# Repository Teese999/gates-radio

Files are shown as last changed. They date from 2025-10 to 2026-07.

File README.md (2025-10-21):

# Умные Ворота - ESP32 DevKit 38 pin

Проект системы управления воротами через различные каналы связи: 433MHz брелки (включая CAME), Wi-Fi (Алиса через Домовенок Кузя) и GSM.

## 📋 Описание

Устройство на базе **ESP32 DevKit 38 pin** для управления воротами через:
- **433MHz брелки** (включая протокол CAME)
- **Wi-Fi** с интеграцией с Алисой
- **GSM модуль SIM800L** (опционально)
- **Дисплей ST7789** 240x240 для визуального интерфейса
- **Джойстик** для навигации по меню

## 🛠 Компоненты

### Основные компоненты:
- **ESP32 DevKit 38 pin** - основной контроллер
- **Дисплей GMT130-V1.0 (ST7789)** - цветной TFT 240x240
- **Джойстик KS0008** - модуль с двумя осями и кнопкой
- **Радиомодуль SRX882 v1.3** - приемник 433MHz
- **Светодиод** - индикатор импульса
- **GSM модуль SIM800L** - для приема звонков/SMS (опционально)

### Схема подключения:

| Компонент | GPIO | Описание |
|---|---|---|
| Дисплей SCK | GPIO18 | SPI Clock |
| Дисплей MOSI | GPIO23 | SPI Data |
| Дисплей DC | GPIO2 | Data/Command |
| Дисплей RST | GPIO4 | Reset |
| Дисплей CS | GPIO5 | Chip Select |
| Джойстик VRx | GPIO34 | Ось X (ADC) |
| Джойстик VRy | GPIO35 | Ось Y (ADC) |
| Джойстик SW | GPIO14 | Кнопка |
| 433MHz DATA | GPIO13 | Данные с приемника |
| LED | GPIO12 | Светодиод/Реле |
| GSM TX | GPIO16 | UART2 TX |
| GSM RX | GPIO17 | UART2 RX |

## 🚀 Установка и Настройка

### 1. Установка PlatformIO

На macOS используйте Homebrew:

```bash
brew install platformio
```

### 2. Клонирование и сборка

```bash
cd gates-radio
platformio run
```

### 3. Подключение ESP32

Подключите ESP32 к компьютеру через USB. Найдите порт:

```bash
ls /dev/cu.*
```

### 4. Загрузка прошивки

Если ESP32 определился (например, `/dev/cu.usbserial-*`):

```bash
platformio run --target upload
```

Или укажите порт явно:

```bash
platformio run --target upload --upload-port /dev/cu.usbserial-XXXX
```

### 5. Мониторинг Serial

Для просмотра логов:

```bash
platformio device monitor
```

Или с автоматической загрузкой и мониторингом:

```bash
platformio run --target upload && platformio device monitor
```

## 📱 Первоначальная настройка

### Настройка Wi-Fi

1. При первом запуске устройство создаст точку доступа **SmartGate-Config**
2. Пароль: `12345678`
3. Подключитесь к точке доступа и перейдите на `http://192.168.4.1`
4. Введите данные вашей Wi-Fi сети
5. Устройство перезагрузится и подключится к вашей сети

### Добавление 433MHz ключей

1. В меню выберите "Управление ключами"
2. Нажмите кнопку на брелке
3. Код будет отображен в Serial Monitor
4. Используйте веб-интерфейс или джойстик для добавления кода в список доверенных

## 📚 Структура проекта

```
gates-radio/
├── docs.md                    # Полная документация проекта
├── platformio.ini             # Конфигурация PlatformIO
├── include/                   # Заголовочные файлы
│   ├── DisplayManager.h       # Управление дисплеем
│   ├── InputManager.h         # Управление джойстиком
│   ├── RF433Receiver.h        # Прием 433MHz
│   ├── WiFiManager.h          # Управление Wi-Fi
│   ├── GateControl.h          # Управление воротами
│   └── GSMManager.h           # Управление GSM (опционально)
├── src/                       # Исходные файлы
│   ├── main.cpp               # Главный файл
│   ├── DisplayManager.cpp     # Реализация дисплея
│   ├── InputManager.cpp       # Реализация джойстика
│   ├── RF433Receiver.cpp      # Реализация 433MHz
│   ├── WiFiManager.cpp        # Реализация Wi-Fi
│   ├── GateControl.cpp        # Реализация управления
│   └── GSMManager.cpp         # Реализация GSM
└── lib/                       # Библиотеки проекта
```

## 🔧 Используемые библиотеки

- **Adafruit GFX Library** - графическая библиотека
- **Adafruit ST7735 and ST7789 Library** - драйвер дисплея
- **rc-switch** - работа с 433MHz
- **TinyGSM** - работа с GSM модулем
- **Preferences** - хранение настроек (встроенная)
- **WiFi** - работа с Wi-Fi (встроенная)
- **WebServer** - веб-сервер (встроенная)

## 📝 Функциональность

### ✅ Реализовано:
- ✅ Инициализация всех модулей
- ✅ Дисплей с меню
- ✅ Навигация джойстиком
- ✅ Прием 433MHz сигналов
- ✅ Сохранение доверенных ключей
- ✅ Wi-Fi подключение
- ✅ Веб-интерфейс для настройки
- ✅ Управление воротами (импульс на GPIO12)

### 🚧 В разработке:
- 🚧 Интеграция с Алисой (Домовенок Кузя)
- 🚧 Полная реализация GSM модуля
- 🚧 Расширенное меню на дисплее
- 🚧 Добавление/удаление ключей через дисплей

## ⚠️ Важные замечания

### Питание GSM модуля
**ОЧЕНЬ ВАЖНО!** GSM SIM800L требует отдельного источника питания 5V с током до 2А. **НЕ ПИТАЙТЕ** его от ESP32 или USB порта компьютера напрямую!

### Антенна 433MHz
Для стабильной работы приемника припайте антенну длиной ~17 см к антенному пину SRX882.

### Подключение реле
Для реального управления воротами замените светодиод на релейный модуль (1-канальный, 5В с опторазвязкой).

## 🐛 Отладка

### Просмотр логов:
```bash
platformio device monitor --baud 115200
```

### Очистка и пересборка:
```bash
platformio run --target clean
platformio run
```

### Проблемы с портом:
Если ESP32 не определяется, установите драйвер:
- **CH340**: https://github.com/adrianmihalko/ch340g-ch34g-ch34x-mac-os-x-driver
- **CP2102**: https://www.silabs.com/developers/usb-to-uart-bridge-vcp-drivers

## 📖 Дополнительная информация

Полное описание подключения, схемы и детальная документация находятся в файле `docs.md`.

## 🤝 Контакты

Для вопросов и предложений обращайтесь к автору проекта.

## 📄 Лицензия

Проект разработан для личного использования.

---

**Версия:** 1.0.0  
**Дата:** Октябрь 2025  
**Платформа:** ESP32 DevKit 38 pin

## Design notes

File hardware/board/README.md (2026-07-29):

# Монтажная плата «Умные Ворота»

Раскладка устройства на протоплате 100 × 150 мм: где стоит каждый модуль, каким проводом
идёт каждая цепь и в каком порядке всё это паять.

| Файл | Что это |
|---|---|
| `board.json` | Источник правды: плата, зоны, компоненты с пинами, цепи с маршрутами, шаги сборки |
| `index.html` | 3D-вьюер: открывается двойным кликом с диска, крутится мышью, показывает верх и низ платы |
| `viewer.js`, `viewer.css` | Исходники вьюера |
| `build.mjs` | Собирает `index.html`, вшивая в него `board.json` (нужно, потому что `fetch` из `file://` запрещён) |
| `validate.py` | Проверка раскладки: наложения, висящие пины, битые ссылки в шагах |
| `lint_routes.py` | Линт однослойной разводки: наложения проводов, общие пайки, перекрёстки, островок 220 |
| `gen_sheets.py` | Генератор печатных листов: нарезка проводов, зеркальный чертёж низа, прозвонка |
| `assembly-sheets.html` | Сгенерированные листы — печатать и паять |

Правки вносятся **только в `board.json`**, дальше:

```bash
python3 hardware/board/validate.py && python3 hardware/board/lint_routes.py && python3 hardware/board/gen_sheets.py && node hardware/board/build.mjs
```

## Как читать разводку

Разводка однослойная, под платой. Каждая цепь идёт **своим цветом** и **своей полосой** —
два провода нигде не делят коридор или отверстие. Короткие прямые связи — «дорожки»:
голая лужёная проволока, пропаянная на каждом пятачке по пути (в вьюере — серебро с
каплями припоя; кладутся первыми). Всё остальное — изолированный провод. Точки, где
провод проходит **поверх** другой цепи, помечены янтарными кольцами — таких пересечений
50, все перпендикулярные; наложений вдоль и общих паек нет (гарантирует `lint_routes.py`).
Сеть 220 В — только изолированный ПуГВ и только в островке 220.

## Система координат

Отверстие адресуется как `[колонка, ряд]`, начало — левый верхний угол.
Колонки 1…55 идут слева направо и **совпадают с заводской нумерацией 01–55**, напечатанной
вдоль длинных сторон платы; рядов 37 (сверху вниз, 100 мм), шаг 2.54 мм — каждому ряду
соответствует заводская буква у западного края: ряды 1–26 = A–Z, ряды 27–37 = снова A–K.
Овальные столбцы по коротким сторонам в нумерацию не входят («колонка 0» на западе, «56»
на востоке); буквенный край платы = левый край вьюера (сторона GSM). Крепёжные отверстия врезаются в углы сетки — соседние с ними пятачки
не используются.

Модули стоят сверху, вся разводка — снизу. Провода свободно проходят под корпусами модулей,
поэтому в маршруте электрически значимы только те точки, где провод действительно
припаивается: концы и промежуточные пятачки с деталями.

## Почему именно такая раскладка

**Две антенны разнесены по диагонали платы.** CC1101 с разъёмом SMA сидит у правого края,
SIM800L с пигтейлом IPX — у левого; между ними 107 мм. GSM-передатчик в момент регистрации
в сети — самый громкий источник помех в корпусе, а приёмник 433 МГц — самый чувствительный
потребитель тишины. Понижайки, вторые по шумности, тоже отодвинуты от радио.

**Земля — звездой, а не гирляндой.** На макетке земли шли цепочкой через выводы понижаек, и
токи GSM-пиков текли по тем же участкам, что и земля приёмника. Здесь от узла у выхода −V
сетевого модуля расходятся три независимых луча: силовой к эмиттерам транзисторов, GSM
(вход понижайки 4 В) и вход понижайки 5 В. Дальше каждый потребитель возвращает ток своей
паре: земля логики идёт с GND ESP32 парой с проводом 5 В на выход понижайки (минусы входа
и выхода у неизолированного LM2596 — один узел), земля радио подцеплена к земле ESP32,
потому что CC1101 питается от его же 3.3 В — возврат идёт туда, откуда пришло питание.
Отдельный обратный провод для реле, найденный на макетке опытным путём, стал штатным
лучом звезды.

**Путь 4 В к SIM800L — самый короткий силовой на плате** (31 мм по прямой), а конденсатор
2200 мкФ стоит вплотную к пинам модуля. Пики до 2 А берутся из конденсатора, а не тянутся
через плату; иначе модуль перезагружается при выходе в сеть.

**220 В — компактный островок у нижнего края.** Весь сетевой кластер — клеммник ввода
ACIN, держатель предохранителя, клеммник привода ACOUT, контакты реле и сетевая половина
модуля IRM-10-12 — собран в зоне 220 (колонки 15–35, ряды 27–37). Сетевые перемычки, как и
вся остальная разводка, идут ПОД платой (сверху — только корпуса), но строго в пределах
островка: туда не заходит ни одна низковольтная трасса, а после пайки островок покрывается
лаком с обеих сторон. Оба клеммника стоят зажимами к нижнему краю — внешние кабели заходят
в них С ТОРЦА, горизонтально; это единственные провода над платой.

## Что находится вне платы

Вся сеть 220 В живёт на плате; в корпусе остались только точки входа-выхода.
В `board.json` они описаны в секции `enclosure`, чтобы картина не обрывалась на краю платы:

| Узел | Роль |
|---|---|
| Гермоввод PG9 «щиток» | южная стенка (x=88 в case.scad): кабель от автомата, жилы L/N спускаются вдоль стенки в зажимы ACIN |
| Гермоввод PG9 «привод» | южная стенка (x=52): три жилы с ACOUT — «открыть» (коричневая), «закрыть» (чёрная), общий (синяя) |
| Привод ворот | получает фазу с NO K1 («открыть») или NO K2 («закрыть»), общий провод — ноль |

Проёмы гермовводов подняты выше компонентов (42 мм от дна — иначе гермоввод, уходящий
внутрь на 10–15 мм, упёрся бы в клеммники), поэтому кабель после ввода опускается вдоль
стенки и заходит в зажимы горизонтально. **Ни один внешний провод не припаян к плате** —
всё под винтами клеммников.

## Что проверить своим железом до пайки

Два посадочных места уже сверены с реальными модулями, одно осталось под проверку:

- **реле HF46F-G** (`"fit": "verify"`) — расстояния между выводами по даташиту не кратны
  2.54 мм; приложить реле к плате, и если не попадает — подпаять к ножкам короткие проводки;
- **ESP32 DevKit** — ✅ подтверждено по факту: узкий клон 27×55 мм, межрядное 22.86 мм
  (между гребёнками ровно 8 свободных рядов). Северный ряд — C, колонки 21–39;
  сажать в две планки PBS и вставлять сборкой;
- **CC1101** — ✅ подтверждено: модуль D-SUN 27×15 мм с разъёмом 2×4, SMA на восток.
  Вид сверху: западная колонка MISO/SCK/GDO0/GND, восточная (ближняя к SMA)
  GDO2/MOSI/CSN/VCC, сверху вниз.

## Связанные документы

- [`../connections.md`](../connections.md) — электрическая схема и BOM
- [`../breadboard-dump.md`](../breadboard-dump.md) — снимок сборки на макетках, откуда всё переносится
- [`../../CLAUDE.md`](../../CLAUDE.md) — прошивка, пины, архитектура

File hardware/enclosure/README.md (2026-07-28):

# Корпус под 3D-печать

Влагозащищённый низкопрофильный корпус для «Умных Ворот» (ревизия r3): без
вентиляционных щелей, кабели только через гермовводы, антенны через SMA-гнёзда.

| Файл | Что это |
|---|---|
| `case.scad` | Параметрическая модель (OpenSCAD): корпус + крышка |
| `stl/case_body.stl` | Готовый корпус, 166 × 116 × 55 мм (в сборе с крышкой 58) |
| `stl/case_lid.stl` | Крышка с фальцем и канавкой под уплотнитель |

## Компоновка внутри

```
Крышка (уплотнитель — силиконовый шнур 2 мм в канавке фальца)
──────────────────────────────────────────────
Одна плата 10x15 на 4 стойках (8 мм — под платой разводка).
Сетевой AC-DC модуль IRM-10-12 стоит прямо на плате в зоне 220.
──────────────────────────────────────────────
Дно 3 мм
```

Отверстия в стенках (все позиции — в `case.scad`, меняются параметрами):

- **2 × SMA Ø6,5** — радио 433 (правая стенка) и GSM-пигтейл (левая), на уровне модулей.
- **Дальняя стенка** — два гермоввода PG9 (Ø15,2): ввод 220 из щитка и кабель к приводу.
  Отверстия под предохранитель нет: он стоит на плате, вставка меняется при снятой крышке.

**Почему гермовводы подняты на 42 мм от дна.** Внутрь корпуса они уходят на 10–15 мм и
на уровне платы упирались бы в реле и сетевой модуль. Подняты выше самой высокой детали
в этой полосе: зазор снизу 5 мм, до крышки 5 мм.

## Печать

- **Материал: PETG или ASA.** Корпус живёт у ворот, внутри греется БП — PLA
  поплывёт в первое же лето. Для сухого отапливаемого помещения допустим PLA.
- Ориентация: обе детали дном вниз, поддержки не нужны (отверстия в стенках
  печатаются мостами, Ø15 мост PETG тянет нормально; при желании — поддержки
  только в отверстиях).
- 4+ периметра, заполнение от 25 %, слой 0,2–0,28.
- **Резьба нигде не печатается**: во все бобышки (4 стойки платы, 8 бобышек
  нижнего яруса, 4 крышечных) паяльником запрессовываются латунные вставки M3.
- Уплотнение крышки: силиконовый шнур Ø2 мм в канавку фальца (или тонкий слой
  силиконового герметика по фальцу).

## Пересборка STL после правки параметров

```bash
/Applications/OpenSCAD-2021.01.app/Contents/MacOS/OpenSCAD \
  -o stl/case_body.stl -D 'part="body"' case.scad
/Applications/OpenSCAD-2021.01.app/Contents/MacOS/OpenSCAD \
  -o stl/case_lid.stl  -D 'part="lid"'  case.scad
```

Габариты и позиции завязаны на раскладку [`../board/board.json`](../board/board.json):
поменял раскладку — проверь параметры в шапке `case.scad`.

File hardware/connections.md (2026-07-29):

# Умные Ворота — схема соединений платы

> Источник распиновки ESP32 — `CLAUDE.md`/`src/main.cpp`. Параметры реле HF46F-G/012-HS1T — по даташиту Hongfa HF46F.
> **Все цоколёвки перед пайкой сверять с даташитом конкретного компонента и прозвонкой** (см. `tasks/lessons.md`).

## Компоненты (BOM)

| Ref | Компонент | Номинал / вариант | Корпус | Кол-во |
|---|---|---|---|---|
| U1 | ESP32 DevKit | 38-pin | модуль | 1 |
| U2 | CC1101 | 433 МГц, 8-pin | модуль | 1 |
| U3 | SIM800L | GSM 2G | модуль | 1 |
| K1, K2 | Реле HF46F-G/012-HS1T | катушка 12 В (720 Ω), контакт SPST-NO 7 A | THT | 2 |
| Q1, Q2 | NPN транзистор | BC337 (или 2N2222/S8050) | TO-92 | 2 |
| D1, D2 | Диод (снаббер катушки) | 1N4007 | DO-41 | 2 |
| R1, R2 | Резистор базы | 1 kΩ 0.25 W | THT/0805 | 2 |
| C1 | Конденсатор (питание SIM800L) | 2200 µF / 10 V электролит | THT | 1 |
| C2 | Конденсатор (развязка SIM800L) | 100 nF керамика | 0805/THT | 1 |
| U4 | DC-DC понижающий | 12 В → 4.0 В (LM2596), выход ≥2 A | модуль | 1 |
| U5 | DC-DC понижающий | 12 В → 5.0 В (LM2596) для ESP32 | модуль | 1 |
| PWR | Сетевой AC-DC модуль | Mean Well **IRM-10-12** (220 VAC → 12 В / 0.85 A / 10.2 Вт), 45.7×25.4×21.5 мм (Case 222A) | PCB | 1 |
| ACIN | Клемма 220 В | вход фазы (после предохранителя) и ноля | screw 2p | 1 |
| FU1 | Держатель предохранителя | закрытый 5×20 top-loading (вставка вынимается вверх, напр. Stelvio PTF/78), **на плату**; вставка **T3.15A** медленная, керамика, 250 В | PCB | 1 |
| ACOUT | Клемма привода | «открыть», «закрыть», общий | screw 3p | 1 |

## Дерево питания (сетевой модуль на плате)

```
220 VAC ── гермоввод ──┬── ACIN.L ── FU1 (3.15 A, на плате) ──┬── PWR AC/L
                       │                                      └── COM K1 ─ перемычка ─ COM K2
                       └── ACIN.N ──┬── PWR AC/N
                                    └── ACOUT.COM (общий провод привода)
NO K1 ── ACOUT «открыть»        NO K2 ── ACOUT «закрыть»

PWR (IRM-10-12) ── 12 В ──┬── катушки реле K1/K2 (через диоды 1N4007)
                          ├── U5 (DC-DC) ── 5 В ── ESP32 «5V»/VIN
                          └── U4 (DC-DC) ── 4.0 В ── SIM800L VCC (+ C1 2200µF, C2 100nF)
ESP32 3V3 (выход) ── CC1101 VCC
Земля — звездой от вывода −V модуля: силовой луч к эмиттерам, GSM, логика.
```

- **ESP32 питается 5 В на пин «5V»/VIN** (от U5), НЕ на 3V3. USB не используется (прошивка по воздуху).
- **SIM800L НЕ питать от 5 В / 3.3 В** — только 3.4–4.4 В (номинал 4.0 В), пики тока до 2 А. C1 2200 µF у самого VCC обязателен, иначе просадки → ребут модуля.
- **CC1101** — от 3.3 В (с пина ESP32 3V3), НЕ от 5 В.
- **Конденсаторы 2200 µF рассчитаны на 10 В** — их место только на шине 4 В. Для буфера по шине 12 В нужен отдельный, на 25 В.

### Бюджет мощности — 10 Вт хватает
Средний расход: ESP32 с Wi-Fi ~1 Вт, SIM800L в среднем 1–1.5 Вт, катушка реле 0.2 Вт →
итого около 2.5–3 Вт из 10. Пики SIM800L (2 А @ 4 В в TDMA-слотах ~577 мкс) берутся из
C1, а не из модуля, поэтому от сети идёт усреднённый ток. Запас примерно трёхкратный.
Если при регистрации в сети всё же пойдут ребуты — увеличить C1 до 3300–4700 µF.

### ⚠️ 220 В на плате — обязательные меры
Сетевые точки собраны в один островок (колонки 15–35 раскладки, ряды 27–37): контакты реле,
предохранитель, клеммники ACIN/ACOUT и сетевые пины модуля. Оба клеммника — зажимами к
нижнему краю платы: внешние кабели заходят с торца, от гермовводов в южной стенке.
Фактический минимальный зазор до низковольтных цепей: ~7.6 мм от коридора магистралей
(ряд 26) до выводов предохранителя (ряд 29) и ≥10 мм до контактов реле; неустранимые
10.2 мм — между катушечными и контактными выводами самого корпуса HF46F. Компенсируется
обязательной прорезью по границе островка и лакировкой с обеих сторон. При сборке:
1) высверлить соседние неиспользуемые пятачки вокруг сетевых пинов;
2) по границе островка пропилить прорезь в текстолите;
3) после пайки покрыть островок изолирующим лаком с обеих сторон;
4) сетевые перемычки вести проводом ПуГВ по нижней стороне платы (как всю разводку),
   строго в пределах островка 220 и не по меди пятачков.

## Соединения — сигналы

### CC1101 (SPI + RAW), U2 ↔ U1

| CC1101 | ESP32 GPIO | Цепь |
|---|---|---|
| VCC | 3V3 | +3V3 |
| GND | GND | GND |
| CSN | 5 | CC1101_CSN |
| SCK | 18 | SPI_SCK |
| MISO (SO) | 19 | SPI_MISO |
| MOSI (SI) | 23 | SPI_MOSI |
| GDO0 | 4 | CC1101_GDO0 (RAW data) |
| GDO2 | 2 | CC1101_GDO2 (clock) |

Модуль — D-SUN 27×15 мм, разъём 2×4 (шаг 2.54). Вид сверху при SMA вправо (на восток,
как стоит на плате): дальняя от SMA колонка — MISO, SCK, GDO0, GND (сверху вниз),
ближняя к SMA — GDO2, MOSI, CSN, VCC. Нечётные пины 1/3/5/7 — ряд GND, чётные 2/4/6/8 — ряд VCC.

### SIM800L (UART2), U3 ↔ U1

| SIM800L | ESP32 | Примечание |
|---|---|---|
| VCC | 4.0 В (U4) | не от 5/3.3 В! |
| GND | GND | общая земля |
| TXD | GPIO16 (RX2) | GSM_TXD → ESP32 RX |
| RXD | GPIO17 (TX2) | ESP32 TX → GSM_RXD, **через делитель** (см. ниже) |

- Логика SIM800L — 2.8 В. Приём (SIM TXD 2.8 В → ESP32 3.3 В RX) работает напрямую. Передача (ESP32 3.3 В TX → SIM RXD) — через делитель **5.6 кОм / 20 кОм** (≈2.6 В, центр окна логики 2.8 В; вариант 10к/20к даёт 2.2 В — впритык к порогу VIH 2.1 В, не использовать).
- Сравнение номеров — по последним 10 цифрам; PIN на SIM отключить (см. CLAUDE.md).

### Драйверы реле (2 канала), U1 → Q → K

| Цепь | Соединения |
|---|---|
| RELAY1_DRV | ESP32 GPIO12 → R1(1 kΩ) → база Q1 |
| RELAY2_DRV | ESP32 GPIO13 → R2(1 kΩ) → база Q2 |
| Q1 эмиттер | GND |
| Q2 эмиттер | GND |
| K1 катушка A | коллектор Q1 **и** анод D1 |
| K1 катушка B | +12 В **и** катод D1 (полоска) |
| K2 катушка A | коллектор Q2 **и** анод D2 |
| K2 катушка B | +12 В **и** катод D2 (полоска) |

Реле развёрнуты катушками к транзисторам (влево), контактами — к зоне 220 (вправо):
низковольтная и сетевая половины схемы не перемешиваются.

- **D1/D2 обязательны** (гасят выброс катушки). Катод (полоска) → +12 В.
- GPIO12 — strapping-пин: база через резистор к транзистору тянет пин к ~0 В при старте (это как раз нужный LOW), конфликта нет.

### Контакты реле (сухие, изолированные)

| Реле | COM | NO | Назначение |
|---|---|---|---|
| K1 | фаза с ACIN | провод «открыть» привода | замыкает фазу на вход «открыть» |
| K2 | фаза с ACIN (перемычка от COM K1) | провод «закрыть» привода | замыкает фазу на вход «закрыть» |

Контакт замыкается при срабатывании реле (SPST-NO). Версия /012-HS1T: контакты AgSnO₂,
10 A — для привода с многократным запасом. Общий провод привода — с клеммы ACOUT.COM; ноль на неё приходит перемычкой с ACIN.N по
нижней стороне платы, внутри островка 220 (вторая ветка нуля — на сетевой пин модуля).

## Определение выводов HF46F-G/012 мультиметром (не по картинке)

- **катушка** = пара выводов ~**720 Ω**;
- **COM–NO** = обрыв (∞), замыкается при подаче 12 В на катушку.

## Заметки по разводке PCB (для автороутера задать вручную)

- **CC1101 (RF 433 МГц):** сплошная земля-полигон под модулем; антенна/выводной провод — с края платы, **без меди под ним**; VCC-развязка 100 nF у пина; дорожки SPI короткие.
- **SIM800L:** C1 1000 µF максимально близко к VCC/GND модуля; широкие силовые дорожки к нему (пики 2 А); держать подальше от антенны CC1101.
- **Силовые/сигнальные:** земли ключей реле и логики свести в одну точку («звезда») у входного GND; катушечные цепи (12 В, ~17 мА каждая) отдельно от SPI/RF.
- **Реле:** контактный конец смотрит в зону 220; под контактными пятачками с нижней стороны
  платы низковольтных трасс нет — драйверные линии обходят реле слева по колонке 10.
- **Сетевой модуль:** сетевая половина корпуса стоит в зоне 220, выход 12 В смотрит к звезде
  земли. Модуль изолированный, но зазоры вокруг его сетевых пинов обеспечиваем сами.
```

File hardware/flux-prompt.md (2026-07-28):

# Flux.ai — как построить схему «Умные Ворота»

## Шаги в Flux

1. Зайди на **flux.ai** → New Project → Schematic.
2. Добавь компоненты из **community-библиотеки** (иконка поиска деталей, вставляй по одному):
   - `ESP32 DevKitC 38` (или `ESP32-WROOM-32 DevKit 38pin`) → **U1**
   - `CC1101` (модуль) → **U2**
   - `SIM800L` (модуль) → **U3**
   - `MP1584` или `LM2596` (DC-DC понижающий) → **U4** и **U5** (2 шт)
   - `HF46F-G` или `HF46F` (реле) → **K1**, **K2** (2 шт)
   - `BC337` (NPN, TO-92) → **Q1**, **Q2**
   - `1N4007` (диод) → **D1**, **D2**
   - резистор `1k` → **R1**, **R2**
   - конденсатор `2200uF` → **C1**, `100nF` → **C2**
   - `Screw Terminal 2 pin` → **J1** (вход 12В), **J_OPEN**, **J_CLOSE**
3. Открой **Flux Copilot** (панель ИИ справа) и вставь промпт ниже (можно по частям).
4. После разводки схемы → назначь футпринты → перейди в PCB и разводи.

> Питание: внешний БП **Mean Well RS-15-12** (220В→12В) подаётся на J1. На плате его рисовать не нужно — это вход 12В.

---

## Промпт для Flux Copilot (вставляй целиком или блоками)

Ты — помощник по проектированию. Соедини уже добавленные компоненты по списку цепей ниже. Создай именованные цепи и подключи к ним указанные выводы. Не добавляй ничего лишнего.

**Питание:**
- Цепь `+12V`: J1.1, U4.VIN, U5.VIN, K1(вывод катушки COIL_B), K2(COIL_B), D1(катод/K), D2(катод/K)
- Цепь `GND`: J1.2, U1.GND, U2.GND, U3.GND, U4.GND, U5.GND, Q1.E(эмиттер), Q2.E(эмиттер), C1(−), C2(−)
- Цепь `+5V`: U5.VOUT, U1.5V (вход питания ESP32)
- Цепь `+4V0_GSM`: U4.VOUT, U3.VCC, C1(+), C2(+)
- Цепь `+3V3`: U1.3V3, U2.VCC

**CC1101 (SPI + RAW), U1↔U2:**
- `SPI_SCK`: U1.GPIO18, U2.SCK
- `SPI_MISO`: U1.GPIO19, U2.MISO
- `SPI_MOSI`: U1.GPIO23, U2.MOSI
- `CC1101_CSN`: U1.GPIO5, U2.CSN
- `CC1101_GDO0`: U1.GPIO4, U2.GDO0
- `CC1101_GDO2`: U1.GPIO2, U2.GDO2

**SIM800L (UART2), U1↔U3:**
- `GSM_TXD`: U1.GPIO16, U3.TXD
- `GSM_RXD`: U1.GPIO17, U3.RXD

**Драйвер реле 1 (открыть):**
- `RELAY1_DRV`: U1.GPIO12, R1.1
- `Q1_BASE`: R1.2, Q1.B(база)
- `K1_COIL_A`: Q1.C(коллектор), K1(вывод катушки COIL_A), D1(анод/A)

**Драйвер реле 2 (закрыть):**
- `RELAY2_DRV`: U1.GPIO13, R2.1
- `Q2_BASE`: R2.2, Q2.B(база)
- `K2_COIL_A`: Q2.C(коллектор), K2(вывод катушки COIL_A), D2(анод/A)

**Контакты реле (сухие):**
- `GATE_OPEN`: K1.COM, J_OPEN.1
- `GATE_OPEN_NO`: K1.NO, J_OPEN.2
- `GATE_CLOSE`: K2.COM, J_CLOSE.1
- `GATE_CLOSE_NO`: K2.NO, J_CLOSE.2

---

## После разводки — скажи Copilot проверить критичное

- SIM800L питается от `+4V0_GSM` (НЕ 5В/3.3В), рядом C1 2200µF.
- Диоды D1/D2 — снабберы катушек: катод к `+12V`, анод к коллектору. Ориентацию проверь.
- На линии `GSM_RXD` (U1.GPIO17 → U3.RXD) добавь делитель или резистор 1–2 кОм последовательно (ESP32 3.3В → вход SIM800L 2.8В).
- CC1101 — только `+3V3`.

## RF/питание при разводке PCB
- CC1101: земля-полигон под модулем; антенна с края без меди под ней; 100nF у VCC.
- SIM800L: широкие силовые дорожки, C1 у самого VCC; подальше от антенны CC1101.
- Земли ключей и логики свести «звездой» у входного GND.

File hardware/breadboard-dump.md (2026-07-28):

# Текущая сборка на макетках (снимок перед переносом на протоплату)

Две макетки, соединённые в одну: столбцы 1–65 слева направо, ряды сверху вниз
`j i h g f e d c b a` (верхняя макетка) — `−` `+` (рельсы, не используются, стоят проставкой) —
`j i h g f e d c b a` (нижняя макетка).

Внутри одной макетки столбец разделён каналом: `{j,i,h,g,f}` — один узел, `{e,d,c,b,a}` — другой.

## ESP32 DevKit

Стоит мостом через обе макетки, USB-C влево.
Верхний ряд пинов — в ряду `b` **верхней** макетки, нижний — в ряду `h` **нижней**.

| Столбец | 22 | 26 | 27 | 28 | 40 |
|---|---|---|---|---|---|
| Ряд `b` (верх) | 5V | IO13 | GND | IO12 | 3V3 |

| Столбец | 26 | 28 | 29 | 30 | 31 | 32 | 33 | 34 | 39 |
|---|---|---|---|---|---|---|---|---|---|
| Ряд `h` (низ) | IO2 | IO4 | IO16 | IO17 | IO5 | IO18 | IO19 | GND | IO23 |

## CC1101 — подключён проводами в ряд `g` нижней макетки

Совпадает со схемой в `connections.md`, отклонений нет. Антенна SMA вкручена в модуль.

| Провод | Точка | Пин ESP32 |
|---|---|---|
| VCC | 40 верх | 3V3 |
| GND | g34 | GND |
| CSN | g31 | IO5 |
| SCK | g32 | IO18 |
| MISO | g33 | IO19 |
| MOSI | g39 | IO23 |
| GDO0 | g28 | IO4 |
| GDO2 | g26 | IO2 |

## SIM800L — ряд `f` нижней макетки, столбцы 3–8

| Столбец | 3 | 4 | 5 | 6 | 7 | 8 |
|---|---|---|---|---|---|---|
| Пин | GND | TXD | RXD | RST | VCC | NET |

- Конденсатор 1000 мкФ прямо на пинах: минус `g3`, плюс `g7`.
- TXD: `i4` → `g29` (IO16/RX2).
- RXD: `g5` → резистор **10 кОм** → `e14` → провод → `g30` (IO17/TX2).
- Земля: `i3` (низ) → `a3` (верх); `b3` (верх) → `c27` (верх, GND ESP32).
- Резистор **20 кОм** в `c3–d3` (верх) — обе ноги в одном узле, **закорочен, не работает**.
  Нижнего плеча делителя фактически нет; UART живёт на одном последовательном 10к.
- Разъём IPX на модуле есть, антенна не подключена.

## Питание

```
RS-15-12:  +12 → j1 (верх)        −12 → j3 и j33 (верх)
Бак №1 (4,0 В):  выход + → h7 (низ, SIM VCC)     выход − → e3 (верх)
Бак №2 (5,0 В):  вход параллельно баку №1
                 выход + → d22 (верх, 5V ESP32)  выход − → d27 (верх, GND ESP32)
```

Оба бака висят на проводах, не закреплены. ESP32 запитана одновременно от бака №2 и USB.

**Земля не звездой, а гирляндой:** минус БП приходит в столбцы 3 и 33 (группа `f–j`),
логическая земля живёт в группе `a–e` столбца 3, связаны они только через земляной вывод
баков (у неизолированного LM2596 вход и выход общие). Для приёмника это худший вариант —
на протоплате разводится звездой от клеммы J1.

## Реле-блок — со слов, с противоречиями (см. ниже)

- K1: выводы в `j24` и `j22` (верх). K2: `j13` и `j11` (верх).
- Q1 BC337: `h31 h32 h33` (верх). Q2 BC337: `h16 h17 h18` (верх).
- Резисторы 1 кОм: `h32–g32` и `h17–g17`.
- Провод `f32` → `c28` (IO12). Провод `f18` → `c26` (IO13).
- Диоды через провода: `j33` — диод — `b2`; `j19` — диод — `g2`.
- «Минусы»: `f39` → `h31`; `g39` → `g17`.
- Провода: `i33` → `i24`; `i22` → `i1`; `i11` → `b1`.

### Что в этом описании не сходится

1. **Оба резистора 1 кОм закорочены**: `h32` и `g32` — один столбец = один узел (то же для
   `h17`/`g17`). Значит IO12/IO13 сидят на базах BC337 напрямую, без ограничения тока.
2. **Q1 выглядит верно**: эмиттер `h33` в столбце 33 = минус БП (`j33`) — это и есть отдельный
   обратный провод реле; база — столбец 32 ← IO12; коллектор — столбец 31 → `f39`.
3. **Q2 собран иначе**: провод от IO13 приходит в столбец 18 (крайняя ножка), а провод от
   катушек — в столбец 17 (средняя, где резистор). Эмиттер (столбец 16) никуда не подключён.
   В таком виде Q2 работать не может.
4. **Оба «минуса» катушек в столбце 39** — это один узел, то есть катушки K1 и K2 соединены
   параллельно и висят на одном коллекторе.
5. **`i33` → `i24`** сажает вывод K1 (столбец 24) прямо на минус БП, минуя транзистор.

Пункты 3–5 требуют сверки по фото: в описанном виде реле либо не управляются, либо
включены постоянно.

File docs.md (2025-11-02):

# Умные Ворота - Проект на ESP32 (Web Interface)

## Описание проекта

Проект "Умные Ворота" представляет собой систему автоматического управления воротами на базе ESP32 с веб-интерфейсом. Система позволяет управлять воротами через:

*   **433MHz пульты**: Прием сигналов от радиопультов
*   **GSM модуль**: Управление через SMS и звонки
*   **Веб-интерфейс**: Настройка через браузер (192.168.4.1)

## Компоненты

*   **ESP32 DevKit 38 pin**: Основной микроконтроллер с WiFi
*   **Радиомодуль SRX882 v1.3**: Приемник 433MHz
*   **Светодиод**: Для индикации импульса
*   **GSM модуль SIM800L**: Для приема звонков и SMS
*   **WiFi**: Встроенный модуль для веб-интерфейса

## Схема подключения

| CC1101 Pin | ESP32 Pin | Описание |
|---|---|---|
| **VCC** | 3.3V | Питание (НЕ 5V!) |
| **GND** | GND | Земля |
| **SCK** | GPIO18 | SPI Clock |
| **MISO** | GPIO19 | SPI Master In Slave Out |
| **MOSI** | GPIO23 | SPI Master Out Slave In |
| **CSN** (CS) | GPIO5 | Chip Select |
| **GDO0** | GPIO4 | Data Output (основной) |
| **GDO2** | GPIO2 | Преамбула (опционально) |

### Светодиод
- **Анод** → GPIO12 (через резистор 220Ω)
- **Катод** → GND

### GSM модуль SIM800L
- **VCC** → 5V (отдельный источник питания)
- **GND** → GND
- **TX** → GPIO21 (ESP32 RX)
- **RX** → GPIO16 (ESP32 TX)

## Веб-интерфейс

### Доступ к интерфейсу

1. **Подключитесь к WiFi**: `SmartGate-Config`
2. **Пароль**: `12345678`
3. **Откройте браузер**: `http://192.168.4.1`

### Функции интерфейса

#### Главная страница
- Статус WiFi подключения
- Количество настроенных телефонов
- Количество ключей 433MHz
- Управление воротами (открыть/закрыть)

#### WiFi настройка
- Сканирование доступных сетей
- Подключение к выбранной сети
- Ввод пароля

#### Управление телефонами
- Просмотр списка номеров
- Добавление новых номеров
- Настройка действий (SMS/Ring)
- Удаление номеров

#### Управление ключами 433MHz
- Просмотр списка ключей
- Обучение новых ключей
- Удаление ключей

## API Endpoints

### WiFi
- `GET /api/wifi/scan` - Сканирование сетей
- `POST /api/wifi/connect` - Подключение к сети

### Телефоны
- `GET /api/phones` - Список телефонов
- `POST /api/phones` - Добавить телефон
- `DELETE /api/phones/{index}` - Удалить телефон

### Ключи 433MHz
- `GET /api/keys` - Список ключей
- `POST /api/keys/learn` - Обучение ключа
- `DELETE /api/keys/{index}` - Удалить ключ

### Ворота
- `POST /api/gate/open` - Открыть ворота
- `POST /api/gate/close` - Закрыть ворота

## Установка и запуск

### Требования
- PlatformIO
- ESP32 DevKit 38 pin
- Компоненты согласно схеме

### Сборка и загрузка

```bash
# Клонирование репозитория
git clone <repository-url>
cd gates-radio

# Сборка проекта
pio run

# Загрузка на ESP32
pio run --target upload

# Мониторинг логов
pio device monitor
```

### Первый запуск

1. Подключите ESP32 к питанию
2. Подключитесь к WiFi `SmartGate-Config` (пароль: `12345678`)
3. Откройте браузер: `http://192.168.4.1`
4. Настройте WiFi подключение
5. Добавьте телефоны и ключи 433MHz

## Конфигурация

### Пины ESP32

```cpp
// Радиомодуль SRX882 v1.3
#define RF_DATA_PIN 13 // GPIO13 - Data pin

// Светодиод
#define LED_PIN     12 // GPIO12 - Управление светодиодом

// GSM SIM800L (UART2)
#define GSM_RX_PIN  21 // GPIO21 - RX пин для UART2
#define GSM_TX_PIN  16 // GPIO16 - TX пин для UART2
```

### WiFi настройки

- **Access Point SSID**: `SmartGate-Config`
- **Access Point Password**: `12345678`
- **IP Address**: `192.168.4.1`
- **Port**: `80`

## Библиотеки

```ini
lib_deps = 
    bblanchon/ArduinoJson@^7.0.4
    sui77/rc-switch@^2.6.4
    vshymanskyy/TinyGSM@^0.11.7
```

## Структура проекта

```
gates-radio/
├── src/
│   ├── main.cpp              # Основной код
│   ├── RF433Receiver.cpp     # Обработка 433MHz
│   ├── GateControl.cpp       # Управление воротами
│   └── GSMManager.cpp        # GSM модуль
├── include/
│   ├── RF433Receiver.h
│   ├── GateControl.h
│   └── GSMManager.h
├── platformio.ini            # Конфигурация PlatformIO
└── docs.md                   # Документация
```

## Отладка

### Мониторинг логов

```bash
pio device monitor --port /dev/cu.SLAB_USBtoUART --baud 115200
```

### Частые проблемы

1. **Не подключается к WiFi**: Проверьте пароль и сигнал
2. **Не работает веб-интерфейс**: Убедитесь что подключены к `SmartGate-Config`
3. **Не принимает 433MHz**: Проверьте подключение к GPIO13
4. **Не работает GSM**: Проверьте питание 5V и подключение UART

## Безопасность

- **Access Point**: Используйте сложный пароль в продакшене
- **WiFi**: Настройте подключение к защищенной сети
- **GSM**: Ограничьте номера телефонов в белом списке
- **433MHz**: Регулярно обновляйте список ключей

## Развитие проекта

### Планируемые функции
- [ ] Поддержка CAME протокола
- [ ] Интеграция с Алисой
- [ ] Мобильное приложение
- [ ] Логирование событий
- [ ] Уведомления по email

### Возможные улучшения
- [ ] OTA обновления
- [ ] Резервное питание
- [ ] Датчики безопасности
- [ ] Интеграция с умным домом

## Лицензия

MIT License

## Автор

Проект "Умные Ворота" - система управления воротами на ESP32

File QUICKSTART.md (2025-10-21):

# 🚀 Быстрый старт - Умные Ворота

## Шаг 1: Установка драйвера (если нужно)

Если ESP32 не определяется системой, установите драйвер:

### CH340 (самый распространенный):
```bash
brew install --cask wch-ch34x-usb-serial-driver
```

### CP2102:
Скачайте с официального сайта: https://www.silabs.com/developers/usb-to-uart-bridge-vcp-drivers

## Шаг 2: Подключение ESP32

1. Подключите ESP32 к компьютеру через USB
2. Проверьте подключение:
```bash
ls /dev/cu.*
```

Должен появиться порт типа `/dev/cu.usbserial-XXXX` или `/dev/cu.SLAB_USBtoUART`

## Шаг 3: Загрузка прошивки

### Автоматически (рекомендуется):
```bash
./upload.sh
```

### Вручную:
```bash
# Сборка
platformio run

# Загрузка (укажите ваш порт)
platformio run --target upload --upload-port /dev/cu.usbserial-XXXX
```

## Шаг 4: Просмотр логов

```bash
platformio device monitor --baud 115200
```

Для выхода нажмите `Ctrl+C`

## Шаг 5: Настройка Wi-Fi

1. ESP32 создаст точку доступа **SmartGate-Config**
2. Пароль: `12345678`
3. Подключитесь к точке доступа
4. Откройте браузер и перейдите на `http://192.168.4.1`
5. Введите данные вашей Wi-Fi сети
6. Устройство перезагрузится и подключится к вашей сети

## Шаг 6: Тестирование 433MHz

1. Откройте Serial Monitor (см. Шаг 4)
2. Нажмите кнопку на брелке 433MHz
3. В логах появится полученный код:
```
[RF433Receiver] Получен код: 12345678
[RF433Receiver] Длина бит: 24
[RF433Receiver] Протокол: 1
```

## Шаг 7: Добавление доверенного ключа

Временно можно добавить ключ программно в `RF433Receiver::init()` или через веб-интерфейс (в разработке).

## 🔧 Полезные команды

```bash
# Очистка проекта
platformio run --target clean

# Только сборка без загрузки
platformio run

# Загрузка и мониторинг одной командой
platformio run --target upload && platformio device monitor

# Список доступных портов
platformio device list
```

## ❓ Проблемы

### ESP32 не определяется
- Проверьте USB кабель (должен поддерживать передачу данных)
- Установите драйвер (см. Шаг 1)
- Попробуйте другой USB порт
- Перезагрузите компьютер

### Ошибка при загрузке
- Убедитесь, что указан правильный порт
- Проверьте, что Serial Monitor закрыт
- Нажмите кнопку BOOT на ESP32 при загрузке (если есть)

### Serial Monitor не показывает логи
- Проверьте скорость: `115200`
- Нажмите кнопку RST на ESP32
- Убедитесь, что выбран правильный порт

## 📚 Дополнительная информация

- **README.md** - полное руководство
- **docs.md** - детальная документация
- **platformio.ini** - конфигурация проекта

## 🎯 Следующие шаги

1. Подключите дисплей ST7789
2. Подключите джойстик KS0008
3. Подключите приемник SRX882
4. Протестируйте меню на дисплее
5. Настройте доверенные ключи 433MHz
6. Интегрируйте с Алисой (опционально)
7. Подключите GSM модуль (опционально)

---

Удачи! 🚀

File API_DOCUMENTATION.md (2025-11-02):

# API Документация - Умные Ворота с CC1101

## Обзор
Система управления воротами с использованием CC1101 радиомодуля через библиотеку RadioLib.

---

## 🔧 Конфигурация CC1101

### Получить текущую частоту
```
GET /api/frequency
```

**Ответ:**
```json
{
  "frequency": 433.92,
  "rssi": -85
}
```

### Установить частоту
```
POST /api/frequency/set
Content-Type: application/json

{
  "frequency": 433.92
}
```

**Параметры:**
- `frequency` (float): Частота в МГц (диапазон: 300-928 МГц)

**Ответ:**
```json
{
  "success": true,
  "frequency": 433.92
}
```

### Получить конфигурацию CC1101
```
GET /api/cc1101/config
```

**Ответ:**
```json
{
  "frequency": 433.92,
  "rssi": -85,
  "status": "active"
}
```

---

## 🔑 Управление ключами

### Получить список ключей
```
GET /api/keys
```

**Ответ:**
```json
[
  {
    "code": 123456,
    "name": "Ключ 0x1E240",
    "enabled": true,
    "rawData": "1e2403ff",
    "rssi": -75,
    "frequency": 433.92,
    "protocol": "RAW/Custom",
    "modulation": "ASK/OOK",
    "timestamp": 1234567890
  }
]
```

### Активировать режим обучения
```
POST /api/keys/learn
```

**Ответ:**
```json
{
  "success": true,
  "message": "Нажмите кнопку на брелке"
}
```

### Остановить режим обучения
```
POST /api/keys/stop
```

**Ответ:**
```json
{
  "success": true,
  "message": "Режим обучения остановлен"
}
```

### Получить статус режима обучения
```
GET /api/keys/status
```

**Ответ:**
```json
{
  "learningMode": false,
  "keyCount": 5
}
```

### Удалить ключ
```
POST /api/keys/delete
Content-Type: application/json

{
  "code": 123456
}
```

**Ответ:**
```json
{
  "success": true
}
```

### Обновить настройки ключа
```
PUT /api/keys/update
Content-Type: application/json

{
  "code": 123456,
  "name": "Новое имя",
  "enabled": true
}
```

**Ответ:**
```json
{
  "success": true
}
```

---

## 🚪 Управление воротами

### Активировать ворота
```
POST /api/gate/trigger
```

**Ответ:**
```json
{
  "success": true
}
```

---

## 📱 Управление телефонами

### Получить список телефонов
```
GET /api/phones
```

**Ответ:**
```json
[
  {
    "id": "+79991234567",
    "number": "+79991234567",
    "smsEnabled": true,
    "callEnabled": true
  }
]
```

### Добавить телефон
```
POST /api/phones
Content-Type: application/json

{
  "number": "+79991234567",
  "smsEnabled": true,
  "callEnabled": true
}
```

### Обновить телефон
```
PUT /api/phones/update
Content-Type: application/json

{
  "id": "+79991234567",
  "smsEnabled": true,
  "callEnabled": false
}
```

### Удалить телефон
```
POST /api/phones/delete
Content-Type: application/json

{
  "id": "+79991234567"
}
```

---

## 📡 WiFi

### Сканировать сети
```
GET /api/wifi/scan
```

**Ответ:**
```json
[
  {
    "ssid": "MyNetwork",
    "rssi": -65,
    "encryption": 1
  }
]
```

### Подключиться к сети
```
POST /api/wifi/connect
Content-Type: application/json

{
  "ssid": "MyNetwork",
  "password": "password123"
}
```

**Ответ:**
```json
{
  "success": true,
  "ip": "192.168.1.100",
  "ssid": "MyNetwork",
  "rssi": -65
}
```

---

## 🔌 WebSocket Events

### Подключение
```
ws://192.168.4.1:81
```

### События

#### Лог сообщения
```json
{
  "event": "log",
  "data": {
    "message": "Система запущена",
    "type": "success"
  }
}
```

#### Ключ принят
```json
{
  "event": "key_received",
  "data": {
    "code": 123456,
    "rawData": "1e2403ff",
    "rssi": -75,
    "snr": 10.5,
    "frequency": 433.92,
    "protocol": "RAW/Custom",
    "modulation": "ASK/OOK",
    "timestamp": 1234567890
  }
}
```

#### Ключ добавлен
```json
{
  "event": "key_added",
  "data": {
    "code": 123456,
    "name": "Ключ 0x1E240",
    "enabled": true,
    "rawData": "1e2403ff",
    "rssi": -75,
    "frequency": 433.92,
    "protocol": "RAW/Custom",
    "modulation": "ASK/OOK",
    "timestamp": 1234567890
  }
}
```

#### Статус WiFi
```json
{
  "event": "wifi_status",
  "data": {
    "status": "connected",
    "ssid": "MyNetwork",
    "rssi": -65,
    "ip": "192.168.1.100"
  }
}
```

---

## 📊 Информация о принятом ключе в Serial

При обнаружении RF ключа в Serial выводится подробная информация:

```
╔════════════════════════════════════════════════════════════╗
║           ОБНАРУЖЕН RF КЛЮЧ (CC1101)                      ║
╠════════════════════════════════════════════════════════════╣
║ Код (uint32):     123456                                   ║
║ Код (HEX):        0x1E240                                  ║
║ Raw данные:       1e2403ff                                 ║
║ Длина данных:     4                                        ║
║ Протокол:         RAW/Custom                               ║
║ Модуляция:        ASK/OOK                                  ║
║ Частота:          433.92 МГц                               ║
║ RSSI:             -75 dBm                                  ║
║ SNR:              10.50 dB                                 ║
║ Частотная ошибка: 0.15 кГц                                ║
║ Время:            1234567890 мс                            ║
╚════════════════════════════════════════════════════════════╝
```

---

## 🔧 Настройки CC1101

### Пины (по умолчанию для ESP32):
- **CS (CSN)**: GPIO5
- **GDO0**: GPIO4
- **GDO2**: GPIO2
- **SCK**: GPIO18 (SPI)
- **MISO**: GPIO19 (SPI)
- **MOSI**: GPIO23 (SPI)

### Параметры модуляции:
- **Модуляция**: ASK/OOK
- **Битрейт**: 3.79 kbps
- **Ширина полосы RX**: 58 кГц
- **Девиация частоты**: 5.2 кГц
- **Выходная мощность**: 10 dBm

### Поддерживаемые частоты:
- 300-348 МГц
- 387-464 МГц
- 779-928 МГц

**Дефолтная частота**: 433.92 МГц

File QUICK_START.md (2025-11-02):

# 🚀 Быстрый старт - Система Умных Ворот с CC1101

## ✅ Прошивка загружена!

Ваша система готова к работе. Следуйте этой инструкции для первого запуска.

---

## 📱 1. Подключение к WiFi

ESP32 создает точку доступа:
- **SSID**: `SmartGate-Config`
- **Пароль**: `12345678`

1. Найдите WiFi сеть **SmartGate-Config**
2. Подключитесь (пароль: 12345678)
3. Откройте браузер

---

## 🌐 2. Открыть веб-интерфейс

После подключения к WiFi откройте один из адресов:
- `http://192.168.4.1`
- `http://smartgate.local`

Вы увидите главную страницу системы управления воротами.

---

## 🔌 3. Подключение CC1101

### Схема подключения:

```
ESP32          CC1101
─────          ──────
3.3V    ───►   VCC
GND     ───►   GND
GPIO18  ───►   SCK
GPIO19  ───►   MISO/GDO1
GPIO23  ───►   MOSI
GPIO5   ───►   CSN
GPIO4   ───►   GDO0
GPIO2   ───►   GDO2
```

⚠️ **ВАЖНО**: CC1101 работает только на **3.3V**, не 5V!

---

## 🔑 4. Добавление RF ключей

### В веб-интерфейсе:

1. Перейдите на страницу **"Ключи"**
2. Нажмите кнопку **"Начать обучение"**
3. **Нажмите кнопку на вашем RF брелке**
4. Ключ автоматически добавится в систему
5. Дайте ключу понятное имя (например "Мой брелок")

### Что происходит:
- CC1101 ловит RF сигнал от брелка
- Система сохраняет код ключа
- При следующем нажатии ворота откроются автоматически!

---

## 📡 5. Настройка частоты

По умолчанию система работает на **433.92 МГц**.

Если ваши брелки работают на другой частоте:

1. В веб-интерфейсе найдите настройки частоты
2. Введите нужную частоту (например: 315, 868, 433.92)
3. Частота сохранится и применится сразу

**Поддерживаемые диапазоны:**
- 300-348 МГц
- 387-464 МГц (дефолт: 433.92)
- 779-928 МГц

---

## 🔍 6. Просмотр логов (опционально)

Если хотите видеть подробную информацию о работе системы:

### Через терминал:
```bash
screen /dev/cu.usbserial-0001 115200
```

**Выход из screen**: `Ctrl+A`, затем `K` (kill)

### Что вы увидите в логах:

```
╔════════════════════════════════════════════════════════════╗
║           ОБНАРУЖЕН RF КЛЮЧ (CC1101)                      ║
╠════════════════════════════════════════════════════════════╣
║ Код (uint32):     123456                                   ║
║ Код (HEX):        0x1E240                                  ║
║ Raw данные:       1e2403ff                                 ║
║ Протокол:         RAW/Custom                               ║
║ Модуляция:        ASK/OOK                                  ║
║ Частота:          433.92 МГц                               ║
║ RSSI:             -75 dBm                                  ║
╚════════════════════════════════════════════════════════════╝
```

---

## 🎯 7. Тестирование

1. **Добавьте ключ** (шаг 4)
2. **Нажмите кнопку на брелке еще раз**
3. Ворота должны активироваться!
4. В логах вы увидите: `"🚪 Ворота активированы ключом: ..."`

---

## 🔧 Управление ключами

### Включение/отключение ключа:
- В списке ключей есть переключатель
- Отключенные ключи не будут открывать ворота

### Удаление ключа:
- Нажмите кнопку удаления рядом с ключом
- Подтвердите действие

### Переименование:
- Нажмите на имя ключа
- Введите новое имя
- Сохраните

---

## 📱 8. Управление телефонами (GSM - опционально)

Если у вас подключен GSM модуль:

1. Перейдите на страницу **"Телефоны"**
2. Добавьте номер телефона
3. Включите SMS и/или CALL уведомления
4. Система будет открывать ворота по звонку/SMS

---

## ⚙️ API (для разработчиков)

### Примеры запросов:

```bash
# Получить список ключей
curl http://192.168.4.1/api/keys

# Изменить частоту
curl -X POST http://192.168.4.1/api/frequency/set \
  -H "Content-Type: application/json" \
  -d '{"frequency": 433.92}'

# Активировать ворота
curl -X POST http://192.168.4.1/api/gate/trigger
```

Полная документация: [API_DOCUMENTATION.md](./API_DOCUMENTATION.md)

---

## 🆘 Проблемы?

### CC1101 не обнаруживает сигналы:
- ✅ Проверьте подключение проводов (особенно питание 3.3V!)
- ✅ Убедитесь, что частота правильная
- ✅ Проверьте антенну (17.3 см для 433 МГц)
- ✅ Батарейка в брелке не села?

### Слабый сигнал (RSSI < -100):
- 📡 Подключите антенну к CC1101
- 📍 Уменьшите расстояние до брелка
- 🔌 Проверьте качество контактов

### Не могу подключиться к WiFi:
- 🔄 Перезагрузите ESP32
- 📱 Забудьте сеть на телефоне и подключитесь снова
- ⚡ Проверьте питание ESP32 (должно быть стабильным)

---

## 📚 Дополнительная документация:

- [CC1101_SETUP.md](./CC1101_SETUP.md) - Подробная настройка CC1101
- [API_DOCUMENTATION.md](./API_DOCUMENTATION.md) - Все API endpoints
- [docs.md](./docs.md) - Техническая документация

---

## 🎉 Готово!

Ваша система умных ворот с CC1101 готова к работе!

**Основные функции:**
- ✅ Автоматическое открытие по RF ключу
- ✅ Управление через веб-интерфейс
- ✅ Поддержка любых частот (300-928 МГц)
- ✅ Добавление/удаление ключей
- ✅ Real-time логи через WebSocket
- ✅ Сохранение настроек в памяти

**Наслаждайтесь автоматизацией!** 🚀

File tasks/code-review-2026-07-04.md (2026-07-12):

# Ревью кода gates-radio — 2026-07-04

> **Статус исправлений (2026-07-04):** по просьбе пользователя security-находки (C2 auth, CSRF, H5 DoS) пропущены; остальное исправлено. Прошивка собирается (`platformio run` → SUCCESS), фронт собирается (`npm run build` → OK). Детали — в разделе [«✅ Исправлено»](#-исправлено-2026-07-04) в конце файла.

Многоагентное ревью (9 направлений × параллельная адверсариальная верификация каждой находки).
Итог: **54 находки → 43 подтверждено, 11 опровергнуто верификаторами.** Ниже — дедуплицированный список (пересечения между направлениями объединены).

Активный путь приёма: `onInterrupt()` (ISR) → `checkReceived()` → `SubGhzMultiDecoder::feed()`. Известные ограничения из CLAUDE.md (нестабильное имя 24-бит, жадный Keeloq, <=12 бит, TX, rolling code) в отчёт не включены.

---

## 🔴 CRITICAL

### C1. `resetReceived()` может НАВСЕГДА отключить приём RF — ворота перестают открываться
**`src/CC1101Manager.cpp:1291`, `src/main.cpp:1656`, `src/main.cpp:967`**

`checkReceived()` перед `return true` уже переподключил прерывание (CC1101Manager.cpp:1272-1274), т.е. во время обработки ключа в `loop()` приём снова активен. Между этим и вызовом `resetReceived()` выполняются долгие операции: `sendWebSocketEvent()`, `sendLog()`, `saveSystemState()` c `nvs_commit` во flash (десятки мс). При зажатой кнопке брелок шлёт кадры непрерывно (~30-50 мс), поэтому ISR успевает принять следующий пакет, выставить флаги и вызвать `detachRawInterrupt()`. Затем `resetReceived()` **без критической секции** обнуляет `receivedFlag`/`rawSignalReady`, но **не переподключает прерывание**. Путей восстановления нет: `attachRawInterrupt()` вызывается только внутри `checkReceived()` (за guard `if(!receivedFlag||!rawSignalReady) return`, флаги только что стёрты) и в `enterRawReceive()` (только при смене частоты/`init`).

**Отказ:** пользователь держит кнопку → приём мёртв до смены частоты через API или ребута, без сообщений об ошибке. Плюс `rawSignalIndex=0` посреди захвата и `lastInterruptTime=0` без сброса `firstEdgeCaptured` (следующая delta = `micros()-0` трактуется как конец пакета).

### C2. Нет аутентификации на управлении + захардкоженный пароль AP — любой в радиусе Wi-Fi открывает ворота
**`src/main.cpp:1376` (и все `server.on`), `src/main.cpp:1300`**

Ни один `server.on(...)` не проверяет токен/сессию (grep по auth/token/session — пусто). `/api/gate/trigger` безусловно вызывает `triggerGatePulse(500)`, минуя всю логику `isKeyMatch`. При этом `setup()` **всегда** поднимает `WiFi.softAP("SmartGate-Config", "12345678")` — пароль-литерал, не меняется через API. Те же открытые эндпоинты дают вход в обучение (`/api/keys/learn`), удаление/добавление ключей, смену частоты, перезапись Wi-Fi-кредов.

**Отказ:** атакующий во дворе подключается к AP по паролю `12345678` → `POST /api/gate/trigger` → ворота открыты без брелока. Прямой физический вектор; в «Известных ограничениях» это НЕ значится как принятое решение.

**Смежное (CSRF, high):** отсутствие CSRF-токена/кастомных заголовков — любой сайт в браузере жертвы (в той же сети) может сделать POST на `/api/gate/trigger`.

---

## 🟠 HIGH

### H1. `isKeyMatch` слишком мягкий — чужой брелок открывает ворота
**`src/main.cpp:501` (ветка 4) и `src/main.cpp:484` (ветка 3)**

- **Ветка 4 (стр. 496-511):** ключи считаются совпавшими, если короткая `bitString` — префикс ИЛИ суффикс длинной, минимум всего **12 бит**, **без проверки протокола**. TE-проверка пропускается, если `saved.te==0` или `receivedTe==0` (а `lastKey.te` может быть 0). 12 бит = 4096 комбинаций, преамбулы общие у брелоков одного бренда.
- **Ветка 3 (стр. 484-491):** совпадение по `saved.code == received.code` **без учёта bitLength и протокола** (`code` — младшие 32 бита; 12-бит `0xABC` == 24-бит `0x000ABC`). Комментарий на стр. 482 прямо говорит «протокол может быть другим!».

**Отказ:** сохранён CAME 12-бит `0xABC` → чужой Nice/Princeton 24-бит с `0x000ABC` и TE в ±40% → `return true` → ворота открыты посторонним пультом другого протокола.

### H2. `verifyKeySignal()` нигде не вызывается — ворота открываются с первого же кадра
**`src/main.cpp:1598` (определение — 519, объявление — 179)**

Функция адаптивной верификации по N повторам определена, но **не вызывается ни разу** (grep). В радио-пути при `keyExists && enabled` реле дёргается немедленно после `isKeyMatch` (комментарий стр. 1589: «активируем сразу... как Flipper»). CLAUDE.md утверждает обратное. Спроектированный слой защиты от единичного ложного декода полностью обойдён — усиливает H1: достаточно ОДНОГО ошибочно совпавшего кадра.

### H3. Настройки CC1101 из NVS никогда не применяются после перезагрузки
**`src/main.cpp:811`**

`loadSystemState()` читает `bitRate/freqDeviation/rxBandwidth/outputPower` из userdata, но в `setup()` к радио применяется **только частота** (стр. 1269). `setBitRate/setRxBandwidth/setFrequencyDeviation` вызываются лишь в `handleCC1101Settings`. `outputPower` не применяется к железу нигде. Дефолты `3.79f/58.0f` — старая конфигурация, не совпадает с реальной `init()` (20 kbps/135 кГц).

**Отказ:** пользователь ставит `rxBandwidth=270кГц`, приём работает → после ребута радио снова 135 кГц, брелок не открывает ворота, а UI показывает 270 кГц — по интерфейсу причину не найти.

### H4. `/api/wifi/connect` пишет креды в NVS ДО подключения и не проверяет ошибку парсинга
**`src/main.cpp:270`, `src/main.cpp:276`**

`deserializeJson(doc, server.arg("plain"))` без проверки `DeserializationError`. При пустом/битом теле `ssid/password` становятся `""`, затем `systemState` безусловно перезаписывается и сразу `saveSystemState()` — до `WiFi.begin()` и независимо от результата. Ветка ошибки подключения (305-310) ничего не откатывает.

**Отказ:** `POST /api/wifi/connect` с телом `{}` → валидные креды роутера стёрты в userdata → после ребута контроллер не подключится к домашней сети (останется только AP).

### H5. Тело запроса буферизуется в RAM без лимита размера — DoS
**`src/main.cpp:848` (и 270, 878, 912, 1008, 1033, 1124, 1178)**

`server.arg("plain")` читает всё тело в String на куче; ESP32 WebServer берёт `Content-Length` без верхней границы. Свободной кучи ~250-300 КБ.

**Отказ:** неаутентифицированный `POST /api/phones` с телом ~500 КБ → OOM → reset ESP32. Повторяемо любым клиентом.

### H6. Декодер Nice FLO не декодирует ни одного бита (мёртв)
**`include/protocols/ProtoNiceFlo.h:38`**

Фазы state machine рассогласованы: `FoundStart` сохраняет HIGH и переходит в `CheckDur`, но `CheckDur` ждёт снова `if(level)` (HIGH), а после HIGH всегда идёт LOW → ветка `else state=Reset`. `SaveDur` (`if(!level)`) недостижим. У рабочих декодеров (CAME/Princeton) пара бита: `SaveDur` ловит HIGH, `CheckDur` ловит LOW.

**Отказ:** любой пульт Nice FLO нельзя ни обучить, ни распознать.

---

## 🟡 MEDIUM

### Декодеры
- **`CC1101Manager.cpp:887` — `data_2` игнорируется + UB-сдвиг для >64 бит.** Верхние биты длинных протоколов (Nice One 72б, Alutech 72б, KingGates 89б, Somfy Keytis 80б) лежат в `data_2`, который в `checkReceived` не читается. Цикл `dr.data >> b` при `b>=64` — UB (на ESP32 маскируется mod 64). `bitString` для >64-битных ключей строится неверно → обученный ключ никогда не совпадёт.
- **`CC1101Manager.cpp:877` — нет `resetAll()` между буферами.** `feed()` сбрасывает декодеры только при победе. Если за буфер никто не выдал `ready` (частый RAW/Unknown), state machine сохраняют накопленные биты и дописывают импульсы из следующей посылки → возможна «химера» из двух пакетов, способная совпасть с обученным ключом.
- **`ProtoGateTx.h:187` — ProtoChamberlain никогда не эмитит.** Единственный `emitResult` в `SaveDur.else` (требует HIGH), но туда всегда приходит LOW; `CheckDur` на несовпадении делает голый `else state=Reset` без emit. 9 накопленных бит никогда не выдаются.
- **`ProtoBatch3.h:20` — ProtoHoltekHT12X мёртв.** `FoundStart` проверяет `if(!level)` сразу после LOW-преамбулы, но следующий импульс всегда HIGH → вечный Reset. Копипаст-баг: у корректного `ProtoHoltek` (ProtoGateTx.h:78) — `if(level && ...)`.
- **`ProtoBatch2.h:162` — ProtoLegrand теряет половину кодов.** `FirstBit` требует короткий первый HIGH; кадры, где первый бит кодируется длинным HIGH (бит '0'), отбрасываются. В референсе Flipper `LegrandDecoderStepFirstBit` принимает оба варианта.

### Персистентность / логика
- **`main.cpp:425` — `saveSystemState()` не проверяет `doc.overflowed()`.** В ArduinoJson 7 при нехватке heap `add()` молча пропускается, `serializeJson` выдаёт валидный, но неполный JSON → усечённое состояние перезаписывает полное (нет бэкапа/транзакции) → перманентная потеря части ключей.
- **`main.cpp:738` — `loadSystemState()` игнорирует ошибку `deserializeJson`.** Повреждённый blob молча → пустое состояние → перезаписывается пустым.
- **`main.cpp:1529` — ошибка записи NVS при обучении не всплывает.** Ключ остаётся только в RAM, UI сообщает об успехе.
- **`main.cpp:1599` — полная сериализация всего state-blob на КАЖДУЮ активацию ворот (`gateOpenCount++`).** Износ flash + блокировка приёмного цикла на время `nvs_commit`.
- **`main.cpp:287` — блокирующий `delay` до 10 c в `handleWiFiConnect`.** Весь `loop()` замирает: приём RF, WebSocket, остальные HTTP.

### Сеть / вывод
- **`main.cpp:210-216` — WS-JSON собирается конкатенацией без экранирования.** Кавычка в имени ключа/SSID/номере ломает `JSON.parse` на фронтенде (события молча теряются); потенциальный XSS-вектор.
- **`GateControl.cpp:24` — `triggerGatePulse()` держит `delay(500)`.** Блокирует веб-сервер, WebSocket и приём RF на 0.5 c.
- **`main.cpp:1439` — reconnect WiFi каждые 5 c без проверки состояния.** `WiFi.begin()` может бесконечно перезапускать ассоциацию.
- **`main.cpp:31 (GPIO12)` — реле на strapping-пине MTDI.** Задаёт напряжение flash при загрузке; подтяжка реле может мешать старту.

### Фронтенд
- **`App.tsx:198` — `apiCall` не проверяет HTTP-статус.** 400/404/500 трактуются как успех.
- **`SettingsPage.tsx:13` — устаревшие радио-дефолты (3.79 kbps/58 кГц).** «Сброс»/«Сохранить» на свежем устройстве перенастраивает CC1101 и ломает приём.
- **`App.tsx:263` — мёртвые WS-обработчики** `phone_count`/`key_count`/`gate_triggered` (прошивка их не шлёт) → счётчики устаревают.
- **`WiFiPage.tsx:59` — подключение к открытой сети не отражается в UI**, повторные клики шлют параллельные `/api/wifi/connect`.
- **`SettingsPage.tsx:196` — `parseFloat(e.target.value) || 0`** — поле нельзя очистить, стирание мгновенно даёт 0.

---

## ⚪ LOW
- `CC1101Manager.cpp:1566` — `detachInterrupt()` из `IRAM_ATTR` ISR (не ISR-safe).
- `CC1101Manager.cpp:116` — `enterRawReceive()` перенастраивает радио при присоединённом прерывании без предварительного detach.
- `main.cpp:820` — `learningMode` сериализуется в NVS, но при загрузке сбрасывается (мёртвое поле, лишние записи).
- `ProtoPrinceton.h:34` — разный TE для одного ключа (один путь делит на `bits*2`, другой на `bits`).
- `WiFiManager.cpp:19` — модуль полностью мёртв, хранит креды в другом NVS, чем реальный путь.
- `GSMManager.cpp:20` — доверенные номера в стандартном NVS `gsm`, а не в `userdata` (не переживут `erase`, рассинхрон с остальным состоянием).
- `PhonePage.tsx:31` — дубликаты номеров не блокируются; `id==номер`, удаление дубликата рассинхронизирует список.

---

## Рекомендованный порядок исправления
1. **C2 + CSRF** — безопасность ворот (auth-токен на управляющих эндпоинтах, сменить/рандомизировать пароль AP). Самый серьёзный дефект.
2. **C1** — обернуть доступ к ISR-флагам/буферу в критические секции; гарантировать переподключение прерывания после `resetReceived()`.
3. **H1 + H2** — ужесточить `isKeyMatch` (обязательное совпадение протокола+bitLength; поднять минимум бит) и включить `verifyKeySignal` в радио-путь.
4. **H4 + H5** — проверять `DeserializationError`, лимитировать `Content-Length`, писать Wi-Fi-креды только после успешного подключения.
5. **H3, H6, декодеры** — применять NVS-настройки радио в `setup()`; починить/сверить с референсом Flipper мёртвые декодеры (Nice FLO, Chamberlain, HT12X, Legrand) и `data_2`/`resetAll`.

---

## ✅ Исправлено (2026-07-04)

Security (C2 auth, CSRF, H5 DoS) — **пропущены по указанию пользователя**. Сборка: прошивка `platformio run` → SUCCESS (Flash 58.1%), фронт `npm run build` → OK.

### Прошивка
| Находка | Файл | Что сделано |
|---|---|---|
| C1 гонка `resetReceived()` | [CC1101Manager.cpp](src/CC1101Manager.cpp) | `resetReceived()` теперь `detach → resetRawBuffer() → attach` — приём гарантированно переармируется, буфер сбрасывается без гонки с ISR, `lastInterruptTime=micros()` (не 0). |
| MEDIUM `data_2`/UB-сдвиг | [CC1101Manager.cpp](src/CC1101Manager.cpp) | Сборка bitString берёт старшие биты из `data_2`, убран UB-сдвиг uint64 на ≥64 (для протоколов >64 бит). |
| H3 настройки радио не применяются | [main.cpp](src/main.cpp) setup + loadSystemState | В `setup()` после init применяются `setBitRate/setRxBandwidth/setFrequencyDeviation`; дефолты исправлены на 20/135; миграция стирает устаревшие 3.79/58. |
| H4 wifi-креды до подключения | [main.cpp](src/main.cpp) handleWiFiConnect | Проверка `DeserializationError` + пустого SSID; креды пишутся в NVS **только** после успешного подключения. |
| MEDIUM overflow `saveSystemState` | [main.cpp](src/main.cpp) | При `doc.overflowed()` запись отменяется (не затираем полное состояние усечённым), возвращается статус. |
| MEDIUM ошибка NVS при обучении | [main.cpp](src/main.cpp) | `saveSystemState()` → `bool`; при сбое обучение сообщает в UI ошибку, а не «успех». |
| MEDIUM `loadSystemState` глотает ошибку | [main.cpp](src/main.cpp) | Проверка `DeserializationError` с предупреждением в Serial. |
| MEDIUM/LOW износ флеша | [main.cpp](src/main.cpp) | Счётчик открытий не пишет весь blob на каждое срабатывание — троттлинг `persistGateCountThrottled()` (≤ раз/5 мин + flush в loop). |
| MEDIUM WS-JSON без экранирования | [main.cpp](src/main.cpp) | Добавлен `jsonEscape()`; экранированы логи, SSID (`wifi_status`), имена ключей и `rawData` в событиях. |
| MEDIUM блокирующий `delay(500)` ворот | [GateControl.cpp](src/GateControl.cpp)/.h | Импульс сделан неблокирующим: `triggerGatePulse()` + `update()` в loop (millis-overflow-safe). |
| MEDIUM реконнект WiFi каждые 5с | [main.cpp](src/main.cpp) loop | `WiFi.begin()` при потере связи — не чаще раза в 30с. |
| LOW Princeton разный TE | [ProtoPrinceton.h](include/protocols/ProtoPrinceton.h) | Оба пути завершения делят `teSum/bits` (был `/(bits*2)`) — TE стабилен, сравнение по TE не отвергает ключ. |
| MEDIUM висячий указатель в `verifyKeySignal` | [main.cpp](src/main.cpp) | Поля копируются до `erase`/`remove_if` (функция пока не вызывается, но UB устранён). |
| LOW устаревший `printConfig` | [CC1101Manager.cpp](src/CC1101Manager.cpp) | Лог конфигурации показывает реальные 20 kbps / 135 кГц. |

### Фронтенд ([smart-gate-frontend/src](smart-gate-frontend/src))
`apiCall` проверяет HTTP-статус; радио-дефолты в Settings → 20/135; числовые поля можно очистить (нет `|| 0`); мёртвые WS-обработчики убраны, счётчики перезапрашиваются из реального состояния; подключение к открытой сети отражается в UI + блокировка повторных кликов; запрет дубликатов телефонов.

### ⏸️ Намеренно НЕ трогал (нужна проверка на железе / принят риск)
- **H1 `isKeyMatch` / H2 `verifyKeySignal`** — «мягкое» сравнение (12-бит префикс, code без протокола) и immediate-trigger. Ужесточение/включение верификации рискует перестать узнавать реальные CAME/Nero/Keeloq из-за нестабильности имени 24-бит протокола (см. lessons.md). Плюс это security-грань, которую просили пропустить. Чинить с пультами в руках.
- **Мёртвые декодеры Nice FLO / HT12X / Legrand** — подтверждённо мёртвы (инверсия фаз state machine), но включение даёт риск ложных срабатываний против реальных протоколов (Nice FLO стоит 4-м в цепочке — жадный матч затенил бы Nero/Keeloq/Princeton), а проверить без эфира нельзя. Фикс — по одному протоколу с контролируемым TX Flipper.
- **Chamberlain** — физически не принимается: преамбула 39 мс > порога конца пакета в ISR (`MAX_PULSE_US=30000`). Фикс декодера бесполезен без правки ISR (рискованно для CAME/Nice).
- **`resetAll()` между буферами** — межбуферное состояние намеренно нужно Nero Radio (реальный протокол пользователя); слепой сброс регрессировал бы Nero. «Химера» из двух пакетов — редкий теоретический случай.
- **Блокирующий `delay` в handleWiFiConnect/setup** — синхронный `WebServer` не даёт чисто асинхронный ответ; блокировка идёт только на явно инициированное пользователем подключение.

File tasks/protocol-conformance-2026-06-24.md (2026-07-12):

# Тест соответствия протоколов: Flipper Zero TX → ESP32+CC1101 RX

**Дата:** 2026-06-24 · **Частота:** 433.92 МГц · **Метод:** HIL (hardware-in-the-loop)

## Что делали

Flipper Zero (Unleashed) передавал в эфир сигналы по каждому протоколу (`subghz tx_from_file`
из `.sub`-файла с известным Protocol/Key/Bit), а прошивка ворот принимала их по CC1101 и
прогоняла через `SubGhzMultiDecoder`. Сравнивали: **какое имя протокола** и **какой код** вывела
прошивка против того, что реально передал Flipper. По каждому протоколу — 3 повтора × 10 посылок.

- Flipper: `/dev/cu.usbmodemflip_Wh1r4ke1`, внутренний CC1101.
- DUT (прошивка): ESP32 `/dev/cu.SLAB_USBtoUART`, 433.92 МГц (переведён с 434.42 через `/api/frequency/set` — на 433.92 эфир заметно тише).
- Парсинг лога DUT: строки `[CC1101] Flipper-декодер: <proto>, <bits> бит, код: 0x<hex>` и `🔑 Ключ:`.

## ⚠️ Важные оговорки (как читать результаты)

1. **Это сравнение «сигнал Flipper → приём прошивки», а не «реальный брелок → прошивка».**
   Энкодер Flipper может давать тайминги, чуть отличающиеся от оригинального пульта. Особенно
   критично для CAME (см. ниже): прошлый «BREAKTHROUGH»-коммит декодировал **реальные** пульты,
   а здесь — переизлучение Flipper.
2. **12 протоколов Flipper Unleashed физически не умеет передавать** (нет TX-энкодера → `Error
   transmitter`). Их «провал» — это ограничение Flipper, **не вина прошивки ворот**. Они вне зачёта.
3. **Часть тест-векторов сгенерирована** (произвольный ключ нужной разрядности). Если у протокола
   нестандартная разрядность/структура, Flipper излучит «не тот» кадр, и прошивка законно его не
   возьмёт. Поэтому `NODECODE` на сгенерированном векторе = **«требует канонического вектора»**, а не
   доказанный баг. Надёжные выводы — только по **реальным захваченным** файлам (📁 в таблице).
4. **Роллинг-коды**: «прошёл» = прошивка вывела правильное **имя протокола** (крипто/счётчик она и
   не валидирует — известное ограничение, см. CLAUDE.md).

## Итог

- Всего в матрице: **39** протоколов.
- Flipper реально передал: **27**; не смог (нет энкодера): **12** (вне зачёта).
- Из 27 переданных:
  - ✅ **Имя протокола распознано корректно: 9** — Princeton, CAME TWEE, Linear, SMC5326, KeeLoq 📁,
    Nice FloR-S, Somfy Telis, CAME Atomo (+ Princeton-кластер).
  - 🟡 **Поймано только как generic OOK (спец-протокол не опознан): 6** — GateTX, Holtek, Phoenix V2,
    Dooya, Security+ 1.0, Mastercode.
  - 🔴 **Совсем не декодировалось (NODECODE): 10** — Nice FLO, Holtek HT12X, MegaCode, Magellan,
    Ansonic, Honeywell, Marantec, **Nero Radio 📁**, Star Line, (+ Holtek HT12X 2-й вектор).
  - 🔴 **Декодировано как ЧУЖОЙ протокол (MISDECODE): 3** — **CAME 📁 → Princeton/0x0**,
    Nero Sketch → Keeloq, Hormann → Keeloq.

## Полная таблица

| # | Flipper протокол | exp код | bit | 🔄 | Прошивка декодировала | вердикт |
|---|---|---|---|---|---|---|
| 1 | Princeton | `0xCAFE5` | 24 | | CAME×2, OOK×5 (код CAFE5 ✅) | ✅ EXACT (кластер) |
| 2 | CAME 📁 | `0xFD852B` | 24 | | **Princeton, код 0x0** | 🔴 MISDECODE |
| 3 | CAME TWEE | — | 54 | | **CAME Twee×8** ✅, OOK×1 | ✅ имя верно¹ |
| 4 | Nice FLO | `0xAB1` | 12 | | — | 🔴 NODECODE |
| 5 | GateTX | `0xA5C31` | 24 | | OOK×1 (код F9F3B ✗) | 🟡 только OOK |
| 6 | Holtek HT12X | `0xAB1` | 12 | | — | 🔴 NODECODE |
| 7 | Holtek | `0x123456789A` | 40 | | OOK×2 (код ✗) | 🟡 только OOK |
| 8 | Linear | `0x2AB` | 10 | | **Linear, код 2AB** ✅ | ✅ EXACT |
| 9 | Linear Delta3 | — | 8 | | — | ⚪ TX-FAIL² |
| 10 | Chamb_Code | — | 9 | | — | ⚪ TX-FAIL² |
| 11 | MegaCode | `0xA01234` | 24 | | — | 🔴 NODECODE |
| 12 | Magellan | `0x12345678` | 32 | | — | 🔴 NODECODE |
| 13 | Ansonic | `0x80A` | 12 | | — | 🔴 NODECODE |
| 14 | SMC5326 | `0x1234567` | 25 | | **SMC5326×2, код 1234567** ✅ | ✅ EXACT |
| 15 | Holtek HT12X | `0xCAF` | 12 | | — | 🔴 NODECODE |
| 16 | Phoenix V2 | `0xFFFFFF1234567` | 52 | | OOK×6 (код ✗) | 🟡 только OOK |
| 17 | Honeywell | `0x123456789ABC` | 48 | | — | 🔴 NODECODE |
| 18 | Dooya | `0x123456789A` | 40 | | OOK×7 (код ✗) | 🟡 только OOK |
| 19 | Marantec24 | `0x123456` | 24 | | — | 🔴 NODECODE |
| 20 | KingGates Stylo4k | — | 24 | | — | ⚪ TX-FAIL² |
| 21 | Legrand | — | 18 | | — | ⚪ TX-FAIL² |
| 22 | Doitrand | — | 36 | | — | ⚪ TX-FAIL² |
| 23 | Clemsa | — | 24 | | — | ⚪ TX-FAIL² |
| 24 | Nero Radio 📁 | `0xE9C30001144DFA` | 56 | | — | 🔴 NODECODE |
| 25 | Nero Sketch | `0xEC3001144` | 40 | | **Keeloq×11** (чужой) | 🔴 MISDECODE |
| 26 | Power Smart | — | 42 | | — | ⚪ TX-FAIL² |
| 27 | KeeLoq 📁 | `0x41800438DE004` | 64 | 🔄 | **Keeloq×8** ✅, OOK×4 | ✅ RECOGNIZED |
| 28 | Nice FloR-S | `0xC9A1E…` | 52 | 🔄 | **Nice FlorS×4** ✅, OOK×26, Nero Radio×11 | ✅ RECOGNIZED³ |
| 29 | BFT | — | 64 | 🔄 | — | ⚪ TX-FAIL² |
| 30 | Somfy Telis | — | 56 | 🔄 | **Somfy Telis×28** ✅, Somfy Keytis×14 | ✅ RECOGNIZED |
| 31 | Faac SLH | — | 64 | 🔄 | — | ⚪ TX-FAIL² |
| 32 | Star Line | — | 64 | 🔄 | — | 🔴 NODECODE |
| 33 | Security+ 2.0 | — | 62 | 🔄 | — | ⚪ TX-FAIL² |
| 34 | Security+ 1.0 | `0x3123…` | 42 | 🔄 | OOK×2 (чужой) | 🟡 только OOK |
| 35 | Hormann HSM | — | 44 | 🔄 | **Keeloq×57** (чужой) | 🔴 MISDECODE |
| 36 | Alutech AT-4N | — | 72 | 🔄 | — | ⚪ TX-FAIL² |
| 37 | CAME Atomo | — | 62 | 🔄 | **CAME Atomo×6** ✅, OOK×24, CAME Twee×4 | ✅ RECOGNIZED |
| 38 | iDo | — | 40 | 🔄 | — | ⚪ TX-FAIL² |
| 39 | Mastercode | `0xA12345678` | 36 | 🔄 | OOK×8 (чужой) | 🟡 только OOK |

¹ CAME Twee преобразует ключ при кодировании — поэтому «код» прошивки ≠ сырому ключу, это норма; имя распознано верно.
² TX-FAIL = у Flipper Unleashed нет энкодера для передачи (его `Error transmitter`), протокол вне зачёта.
³ Спец-имя появлялось реже, чем OOK/ложные срабатывания (таблица иначе показала бы только топ).

## 🔴 Главные findings (по надёжным — реальным захваченным — векторам)

1. **CAME (реальный ключ Zar1 `0xFD852B`) декодируется в `Princeton / 0x0`** — стабильно, все повторы.
   Прошивка ловит сигнал, но выдаёт мусорный код 0 и неверное имя. Это самый весомый результат:
   вектор канонический (реальный захват), Flipper излучает его честно. **Расходится с заявлением
   git-истории «CAME decode correctly»** — как минимум для переизлучения Flipper CAME-энкодером.
   *Оговорка:* возможно, тайминг CAME-энкодера Flipper ≠ тайминг реального пульта; нужно перепроверить
   реальным пультом CAME.
2. **Nero Radio (реальный `test_nero` `0xE9C3…`) не декодируется вообще (NODECODE).** Тоже реальный
   вектор. Прошивка заявляет поддержку Nero Radio, но переизлучение Flipper не берёт.
3. **KeeLoq (реальный DoorHan) распознаётся как `Keeloq` ✅** — единственный реальный вектор, который
   отработал чисто. Роллинг: имя верно (крипто не проверяем).

## 🟡 Систематические проблемы декодера

- **Нестабильное имя для 24-битных OOK.** Один и тот же сигнал — то `CAME`, то `Princeton`, то `OOK`
  (первый сматчивший декодер побеждает, а CAME/Princeton/GenericOOK все берут 24 бита). Код при этом
  обычно восстанавливается, имя — лотерея. Влияет на сравнение ключей по `(протокол+частота)`.
- **Keeloq-декодер слишком «жадный».** Nero Sketch и Hormann HSM устойчиво уезжают в `Keeloq`
  (Hormann — 57 раз). Keeloq матчит чужие 64-битные/роллинг-кадры.
- **Короткие протоколы (≤12 бит) проваливаются.** Nice FLO(12), Holtek HT12X(12), Ansonic(12) —
  NODECODE. GenericOOK-fallback требует ≥20 бит, а спец-декодеры этих протоколов не сработали.
- **Generic-OOK без распознавания протокола.** GateTX, Holtek, Phoenix V2, Dooya, Mastercode,
  Security+1.0 ловятся только как сырой `OOK`, причём биты часто читаются неверно (код ≠ переданному).

## ⚪ Flipper Unleashed не умеет передавать (TX-FAIL, вне зачёта прошивки)

Linear Delta3, Chamb_Code (Chamberlain), KingGates, Legrand, Doitrand, Clemsa, Power Smart, BFT,
FAAC SLH, Security+ 2.0, Alutech AT-4N, iDo — нет TX-энкодера. Чтобы протестировать их приём, нужен
**реальный пульт** или захват `.sub`, который Flipper умеет переизлучать.

## Замечания по методике / стабильности

- **Flipper уходил в краш USB** при попытке передать неподдерживаемый протокол (`Error transmitter`
  роняет CDC, иногда визуально ребутит Flipper). Харнес сделан дроп-устойчивым (переподключение,
  ранний выход на encode-error, резюмируемость), поэтому прогон дошёл до конца, переживая ресеты.
- **Сильные выводы — только по 📁 реальным векторам** (CAME, Nero Radio, KeeLoq). По сгенерированным
  `NODECODE`/`OOK` — статус «требует канонического вектора», прежде чем называть багом прошивки.

## 🔬 Уточнение корневой причины (анализ сырого приёма CAME)

Пользователь подтвердил: **`Zar1` снят с РЕАЛЬНОГО пульта CAME** (не синтетика). Перепроверка живым
пультом невозможна (пульта нет под рукой), поэтому разобрали, что прошивка **реально принимает**,
когда Flipper переизлучает этот CAME:

```
переходов=86,  TE=1314 мкс, первые переходы: 365H 1764L 815L 544L 314L 581L 315L 287L 407L 290L...
переходов=889, TE=912 мкс
переходов=60,  TE=746 мкс
RSSI: -74 dBm (на всех)
```

Это **искажённая волна, а не чистый CAME** (у CAME ожидается TE≈320 мкс стабильно, ~24 бита):
- TE скачет 746↔912↔1314 мкс; число переходов прыгает 60↔86↔889 на одном сигнале;
- идут **подряд несколько `L`** (`815L 544L 314L`) → короткие `H` между ними **теряются**;
- RSSI −74 dBm на всё (для Flipper вблизи — слабо/шумно).

**Вывод: CAME не декодируется из-за качества приёма, а не из-за таблицы декодера CAME.** Декодер
давится мусором на входе. Это смещает корень на **RX-тракт**, и подтверждается кодом:

1. **Конфиг радио корректен** (не полоса виновата). `init()` ставит `setBitRate(20.0)` /
   `setRxBandwidth(135.0)` / `setOOK(true)` (CC1101Manager.cpp:1418–1422). API-значения
   `3.79 kbps / 58 kHz` — это **устаревшие дефолты `systemState`** (main.cpp:811–813), которые
   просто отдаются наружу, а не реальное состояние регистров. Полоса — 135 кГц, как надо.
2. **Захват импульсов режет короткие фронты.** `onInterrupt` (CC1101Manager.cpp:35–41):
   `MIN_PULSE_US = 200`, `GLUE_THRESHOLD_US = 40`. При дрожании OOK-слайсера на слабом сигнале
   часть `H`-импульсов CAME (te≈320 мкс) уходит ниже порога → дропается/склеивается → 24-битный
   кадр рвётся. Это ровно «подряд `L`» из лога. Длинные избыточные протоколы (KeeLoq 64-бит, Somfy,
   SMC5326) переживают потерю части бит, а короткие точные (CAME, Nice FLO, Holtek) — нет.
3. **Косвенное подтверждение:** Princeton (te=**400** мкс) декодировался ЧИСТО (`0xCAFE5`), а
   CAME (te=**320** мкс) — нет. Чем короче te и чем ближе к порогам/джиттеру, тем хуже.

**RSSI −74 dBm на ВСЁ подряд (и шум, и сигнал)** — отдельно подозрительно: либо приём реально
слабый (антенна/дистанция/слабая внутренняя антенна Flipper на 433), либо чтение RSSI почти
константно (`getRSSI()` отдаёт залипшее значение). Стоит проверить.

## Рекомендации (следующий шаг)

1. **Сначала — качество приёма, а не декодеры.** Главный кандидат в корень — слабый/дрожащий RX.
   Проверить: (а) антенну CC1101 на ESP32 (припой/контакт/длина под 433); (б) поднести Flipper
   вплотную и повторить CAME — если при сильном сигнале CAME декодится, корень = уровень/антенна;
   (в) `getRSSI()` — почему всегда ровно −74 (не залипло ли чтение).
2. **Пересмотреть пороги захвата `onInterrupt`** (CC1101Manager.cpp:35–41) на чистом сильном
   сигнале: `MIN_PULSE_US=200` может резать короткие фронты CAME при джиттере. Менять только после
   п.1 и обязательно с проверкой реальным пультом.
3. **Поправить устаревший вывод API** `bitRate/rxBandwidth` (main.cpp:811–813, 417–419): отдаёт
   `3.79/58` вместо реальных `20/135` — вводит в заблуждение при диагностике.
4. **Перепроверить CAME и Nero Radio реальными пультами** (не Flipper) — снять вопрос «декодер vs
   тайминги Flipper-энкодера» окончательно.
5. **Декодеры — во вторую очередь** (после того как приём чистый): Keeloq не должен матчить
   Nero Sketch/Hormann; 24-битные CAME/Princeton/OOK развести, чтобы имя было стабильным.
6. Харнес — в `scratchpad/conformance/` (matrix/runner/report/hil.py), `results.json`, резюмируемый.

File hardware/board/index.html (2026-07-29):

Монтажная плата

Сверху Снизу Изометрия Сброс ☾ Тёмная

Слои и легенда ▾

#### Разводка (снизу платы)

Питание12 / 5 / 4 / 3.3 В Землязвезда СигналыSPI / UART 220 Впод платой, островок 220

дорожкаголая лужёнка, пайка на каждом пятачке

перекрёстокизолированный провод проходит поверх

каждая цепь — своим цветом и своей полосой: два провода нигде не делят коридор или пайку

#### Сверху платы

Компоненты Зоны Подписи Просветить плату

#### Вне платы

Корпус и кабелистенки и 220 В Корпус (контур)160×110×46

земля (PE)жёлто-зелёная, парковка в клемме

фаза (L)коричневый: предохранитель, реле, «открыть»

жила «закрыть»чёрная, фаза с контакта NO K2

ноль (N)синий, без коммутации

12 В на платупостоянка после БП

Сборка платы ▾

Шаги Монтаж Список Инфо

Назад Вперёд Показать всё

#### Компоненты

#### В корпусе (не на плате)

#### Цепи

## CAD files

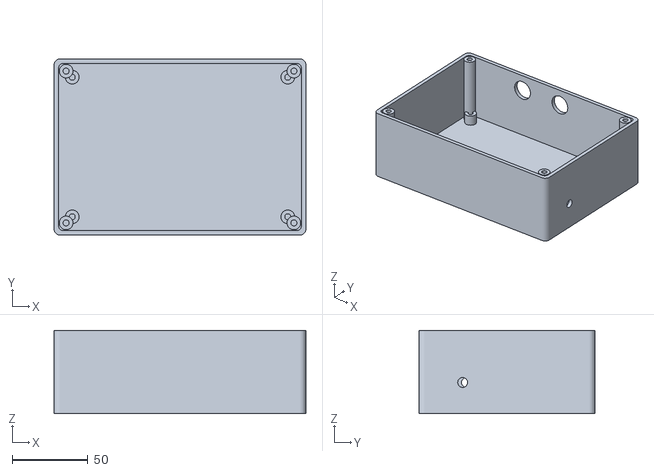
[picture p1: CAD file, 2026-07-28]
hardware/enclosure/stl/case_body.stl
166.0 x 116.0 x 55.0

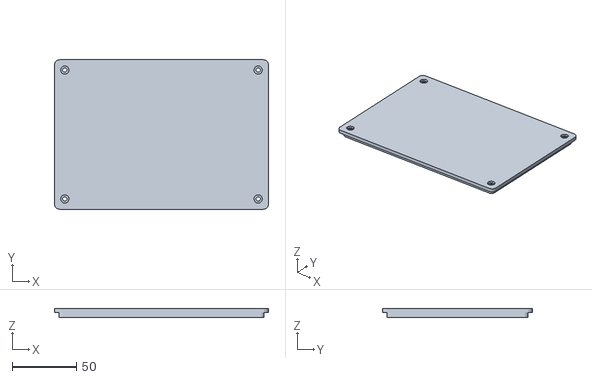
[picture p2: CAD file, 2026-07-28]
hardware/enclosure/stl/case_lid.stl
166.0 x 116.0 x 7.00

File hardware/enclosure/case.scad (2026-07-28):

// ============================================================================
// Умные Ворота — корпус под 3D-печать (ревизия r3)
// ============================================================================
// Компоновка (см. hardware/board/board.json):
//   одна плата 10x15 на стойках; сетевой модуль IRM-10-12 стоит на ней.
// Влагозащита: без вентиляции, крышка с фальцем и канавкой под силиконовый
// шнур 2 мм, кабели — только через гермовводы PG9, антенны — через SMA.
//
// Проёмы в стенках подняты ВЫШЕ компонентов платы: гермовводы уходят внутрь
// на 10–15 мм и на уровне платы упирались бы в реле и сетевой модуль.
// Кабель после гермоввода спускается ВДОЛЬ стенки в зазоре за краем платы
// и заходит жилами в зажимы клеммников горизонтально, с торца (входы
// KF301 смотрят на стенку). Предохранитель стоит на плате, отверстия под
// него в стенке нет — на одну дырку меньше, влагозащита лучше.
//
// Печать: PETG или ASA (на улице PLA плывёт), 4+ периметра, заполнение 25%+,
// дном вниз без поддержек. Резьба нигде не печатается: крышка и стойки — на
// латунных вставках M3 (запрессовать паяльником).
//
// Экспорт STL: openscad -o stl/case_body.stl -D 'part="body"' case.scad
//              openscad -o stl/case_lid.stl  -D 'part="lid"'  case.scad
// ============================================================================

part = "body"; // "body" | "lid" | "preview" (обе детали рядом)

// ---------- основные параметры, мм ----------
wall      = 3;
floor_t   = 3;
lid_t     = 3;
r_out     = 4;

board_x   = 150;   // текстолит 10x15; сетка 58x38 внутри него со смещением от края
board_y   = 100;
grid_off  = [2.6, 3.0];   // от угла платы до центра пятачка [1,1] (см. board.json)
board_t   = 1.6;
standoff  = 8;     // под платой идёт вся разводка
tall_comp = 17;    // самый высокий элемент на плате (электролит 2200 мкФ)

in_x = 160;
in_y = 110;
main_off = [(in_x - board_x)/2, (in_y - board_y)/2];   // [5, 5]

// Пересчёт координат платы в координаты корпуса.
// bm/bym — миллиметры от угла текстолита, bx/by — по сетке пятачков.
function bm(x) = main_off[0] + x;
function bym(y) = main_off[1] + y;
function bx(col) = bm(grid_off[0] + (col - 1) * 2.54);
function by(row) = bym(grid_off[1] + (row - 1) * 2.54);

// Верх компонентов над внутренним дном
comp_top  = standoff + board_t + tall_comp;            // 26.6
// Проёмы в стенках — выше компонентов: половина диаметра PG9 (7.6) плюс
// зазор 5 мм до самой высокой детали и 5 мм до крышки.
pen_z     = floor_t + comp_top + 5 + 7.6;              // 42.2 от наружного дна
in_z      = 52;   // = comp_top + 5 + 7.6 (проём) + 7.6 + 5 запаса, округлено

// ---------- крепёж ----------
insert_d  = 4.0;   // отверстие под латунную вставку M3 (натяг, запрессовка паяльником)
insert_h  = 6;
m3_free   = 3.4;

// Стойки под крепёжные отверстия платы: они в зелёном поле по углам,
// в миллиметрах от угла текстолита (см. board.json -> board.mountingHoles).
main_holes = [ for (xy = [[4,4],[146,4],[4,96],[146,96]]) [bm(xy[0]), bym(xy[1])] ];

// ---------- проёмы в стенках ----------
// Зона 220 на плате — ряды 27..38, то есть у ДАЛЬНЕЙ стенки (y = in_y).
// Туда же выходят оба гермоввода. Роли назначены по клеммникам под ними:
// ACOUT (зажимы в колонках 20-24) — западнее, ACIN (27-29) — восточнее,
// поэтому привод — левый гермоввод, щиток — правый; кабели не перекрещиваются.
pg9_d       = 15.2;   // гермоввод PG9

gland_out_x = 52;     // кабель к приводу с клеммника ACOUT (зажимы ~кол. 22)
gland_in_x  = 88;     // ввод 220 из щитка -> клеммник ACIN (зажимы ~кол. 28)

// SMA-гнёзда: на уровне модулей, ряды 8 (радио, правая стенка) и 9 (GSM, левая)
sma_d       = 6.5;
sma_z       = floor_t + standoff + board_t + 8;
sma_right_y = by(8);
sma_left_y  = by(9);

// Уплотнение крышки: канавка под силиконовый шнур d2
seal_w = 2.6; seal_deep = 1.4;

$fn = 48;
eps = 0.01;

// ---------- заготовки ----------
module rbox(x, y, z, r) {
  hull() for (dx=[r, x-r], dy=[r, y-r]) translate([dx,dy,0]) cylinder(h=z, r=r);
}

module boss(h) {
  difference() {
    cylinder(h=h, d=insert_d+5);
    translate([0,0,h-insert_h]) cylinder(h=insert_h+eps, d=insert_d);
  }
}

// проём в дальней стенке (ось +Y)
module hole_far(x, z, dia) {
  translate([wall+x, wall+in_y-eps, z]) rotate([-90,0,0]) cylinder(h=wall+2*eps, d=dia);
}

// ---------- корпус ----------
module body() {
  difference() {
    rbox(in_x+2*wall, in_y+2*wall, in_z+floor_t, r_out);
    translate([wall, wall, floor_t]) rbox(in_x, in_y, in_z+eps, r_out-1);

    hole_far(gland_in_x,  pen_z, pg9_d);        // ввод 220 из щитка
    hole_far(gland_out_x, pen_z, pg9_d);        // кабель к приводу

    // SMA радио 433 — правая стенка
    translate([wall+in_x-eps, wall+sma_right_y, sma_z])
      rotate([0,90,0]) cylinder(h=wall+2*eps, d=sma_d);
    // SMA GSM — левая стенка
    translate([-eps, wall+sma_left_y, sma_z])
      rotate([0,90,0]) cylinder(h=wall+2*eps, d=sma_d);
  }

  // стойки платы
  for (h = main_holes) translate([wall+h[0], wall+h[1], floor_t]) boss(standoff);

  // бобышки крышки по углам
  for (dx=[wall+5, wall+in_x-5], dy=[wall+5, wall+in_y-5])
    translate([dx, dy, floor_t]) boss(in_z);
}

// ---------- крышка ----------
module lid() {
  difference() {
    union() {
      rbox(in_x+2*wall, in_y+2*wall, lid_t, r_out);
      // фальц, входящий внутрь корпуса
      translate([wall+0.3, wall+0.3, -4])
        difference() {
          rbox(in_x-0.6, in_y-0.6, 4+eps, r_out-1);
          translate([2.5,2.5,-eps]) rbox(in_x-0.6-5, in_y-0.6-5, 4+3*eps, r_out-1);
        }
    }
    // канавка под силиконовый шнур по периметру фальца
    translate([wall+3.4, wall+3.4, -seal_deep])
      difference() {
        rbox(in_x-6.8, in_y-6.8, seal_deep+eps, 2);
        translate([seal_w, seal_w, -eps])
          rbox(in_x-6.8-2*seal_w, in_y-6.8-2*seal_w, seal_deep+3*eps, 2);
      }
    // винты крышки над бобышками
    for (dx=[wall+5, wall+in_x-5], dy=[wall+5, wall+in_y-5])
      translate([dx, dy, -eps]) {
        cylinder(h=lid_t+2*eps, d=m3_free);
        translate([0,0,lid_t-1.8]) cylinder(h=2, d=6.4);  // потай под головку
      }
  }
}

if (part == "body") body();
else if (part == "lid") lid();
else { body(); translate([0, in_y+2*wall+15, 0]) lid(); }

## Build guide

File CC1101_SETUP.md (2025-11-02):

# 📡 Настройка и использование CC1101 с RadioLib

## ✅ Что сделано

### 1. Интеграция библиотеки RadioLib
- ✅ Добавлена библиотека `RadioLib` версии 6.6.0
- ✅ Удалена старая библиотека `rc-switch`
- ✅ Создан модуль `CC1101Manager` для работы с CC1101

### 2. Функционал
- ✅ **Поддержка всех протоколов** через RadioLib (ASK/OOK, FSK, GFSK, MSK)
- ✅ **Выбор частоты** (300-928 МГц, дефолт 433.92 МГц)
- ✅ **Режим обучения ключей** через веб-интерфейс
- ✅ **Автоматическое открытие ворот** по сохраненным ключам
- ✅ **Подробный вывод информации о ключе** в Serial Monitor
- ✅ **API для управления частотой** и настройками
- ✅ **WebSocket** для real-time уведомлений

---

## 🔌 Подключение CC1101 к ESP32

### Полная схема подключения (рекомендуется):

| CC1101 Pin | ESP32 Pin | Описание |
|---|---|---|
| **VCC** | 3.3V | Питание (НЕ 5V!) |
| **GND** | GND | Земля |
| **SCK** | GPIO18 | SPI Clock |
| **MISO** | GPIO19 | SPI Master In Slave Out |
| **MOSI** | GPIO23 | SPI Master Out Slave In |
| **CSN/CS** | GPIO5 | Chip Select |
| **GDO0** | GPIO4 | Data Output (основной) |
| **GDO2** | GPIO2 | Преамбула/Синхронизация |

⚠️ **ВАЖНО**: 
- CC1101 работает ТОЛЬКО на 3.3V! Не подключайте к 5V!
- **GDO2 рекомендуется** для работы с нестандартными брелками и улучшенной синхронизации

---

## 🚀 Установка и запуск

### 1. Установка зависимостей
```bash
cd /Users/daniildavydov/Documents/Work/gates-radio
pio lib install
```

### 2. Сборка проекта
```bash
pio run
```

### 3. Загрузка на ESP32
```bash
pio run --target upload
```

### 4. Мониторинг Serial
```bash
pio device monitor
```

---

## 📱 Использование через веб-интерфейс

### Подключение
1. ESP32 создает WiFi точку доступа: `SmartGate-Config` (пароль: `12345678`)
2. Подключитесь к ней и откройте: `http://192.168.4.1` или `http://smartgate.local`

### Управление частотой
1. В веб-интерфейсе можно изменить частоту приема
2. Частота сохраняется в NVS памяти
3. Доступные диапазоны:
   - 300-348 МГц
   - 387-464 МГц (дефолт: 433.92 МГц)
   - 779-928 МГц

### Добавление ключей
1. Откройте страницу управления ключами
2. Нажмите "Начать обучение"
3. Нажмите кнопку на вашем RF брелке
4. Ключ автоматически добавится в систему
5. Дайте ключу понятное имя

### Удаление ключей
1. В списке ключей нажмите на кнопку удаления
2. Подтвердите действие

### Включение/отключение ключей
1. Каждый ключ можно включить или отключить
2. Отключенные ключи не будут открывать ворота

---

## 🔍 Информация о ключе в Serial Monitor

При обнаружении RF сигнала в Serial выводится:

```
╔════════════════════════════════════════════════════════════╗
║           ОБНАРУЖЕН RF КЛЮЧ (CC1101)                      ║
╠════════════════════════════════════════════════════════════╣
║ Код (uint32):     123456                                   ║
║ Код (HEX):        0x1E240                                  ║
║ Raw данные:       1e2403ff                                 ║
║ Длина данных:     4                                        ║
║ Протокол:         RAW/Custom                               ║
║ Модуляция:        ASK/OOK                                  ║
║ Частота:          433.92 МГц                               ║
║ RSSI:             -75 dBm                                  ║
║ SNR:              10.50 dB                                 ║
║ Частотная ошибка: 0.15 кГц                                ║
║ Время:            1234567890 мс                            ║
╚════════════════════════════════════════════════════════════╝
```

### Параметры:
- **Код (uint32)**: Уникальный код ключа (число)
- **Код (HEX)**: Код в шестнадцатеричном формате
- **Raw данные**: Сырые данные в HEX формате
- **Длина данных**: Количество принятых байт
- **Протокол**: Тип протокола (RAW/Custom для неопределенных)
- **Модуляция**: Тип модуляции (ASK/OOK, FSK и т.д.)
- **Частота**: Текущая частота приема
- **RSSI**: Уровень сигнала (чем выше, тем лучше)
- **SNR**: Соотношение сигнал/шум
- **Частотная ошибка**: Отклонение частоты

---

## 🔧 API Endpoints

### Управление частотой
```bash
# Получить текущую частоту
curl http://192.168.4.1/api/frequency

# Установить частоту
curl -X POST http://192.168.4.1/api/frequency/set \
  -H "Content-Type: application/json" \
  -d '{"frequency": 433.92}'

# Получить конфигурацию CC1101
curl http://192.168.4.1/api/cc1101/config
```

### Управление ключами
```bash
# Получить список ключей
curl http://192.168.4.1/api/keys

# Начать обучение
curl -X POST http://192.168.4.1/api/keys/learn

# Остановить обучение
curl -X POST http://192.168.4.1/api/keys/stop

# Удалить ключ
curl -X POST http://192.168.4.1/api/keys/delete \
  -H "Content-Type: application/json" \
  -d '{"code": 123456}'
```

Полная документация API: [API_DOCUMENTATION.md](./API_DOCUMENTATION.md)

---

## 🎛️ Настройка параметров CC1101

Параметры по умолчанию оптимизированы для стандартных брелков на 433 МГц:

- **Модуляция**: ASK/OOK
- **Битрейт**: 3.79 kbps
- **Ширина полосы RX**: 58 кГц
- **Девиация частоты**: 5.2 кГц

Если ваши брелки работают иначе, можно изменить параметры в `CC1101Manager.cpp`:

```cpp
// Изменить битрейт
cc->setBitRate(9.6); // например, 9.6 kbps

// Изменить ширину полосы
cc->setRxBandwidth(100.0); // например, 100 кГц

// Изменить девиацию
cc->setFrequencyDeviation(10.0); // например, 10 кГц
```

---

## 🐛 Диагностика проблем

### CC1101 не инициализируется
1. Проверьте подключение проводов (особенно питание 3.3V!)
2. Проверьте, что SPI пины правильно подключены
3. Убедитесь, что GDO0 и GDO2 подключены
4. Проверьте Serial Monitor на наличие ошибок

### Ключи не обнаруживаются
1. Убедитесь, что частота правильная (433.92 МГц для большинства брелков)
2. Проверьте RSSI в Serial Monitor (должен быть > -100 dBm)
3. Попробуйте изменить параметры модуляции
4. Убедитесь, что брелок работает (проверьте батарейку)

### Слабый сигнал (низкий RSSI)
1. Подключите антенну к CC1101 (17.3 см для 433 МГц)
2. Уменьшите расстояние до брелка
3. Проверьте, что антенна не экранирована металлом

---

## 📊 Мониторинг системы

### Serial Monitor
- Каждые 30 секунд выводится диагностическая информация
- RSSI и текущая частота
- Статус приема

### WebSocket Events
- Real-time уведомления о принятых ключах
- Логи системы
- Статус WiFi

---

## 🎉 Преимущества RadioLib

- ✅ **Поддержка множества модулей**: CC1101, SX127x, nRF24, и многие другие
- ✅ **Гибкая настройка**: Полный контроль над параметрами
- ✅ **Активная разработка**: Регулярные обновления
- ✅ **Хорошая документация**: https://github.com/jgromes/RadioLib
- ✅ **Поддержка протоколов**: ASK, OOK, FSK, GFSK, MSK, LoRa, и другие

---

## 📚 Дополнительные ресурсы

- [RadioLib GitHub](https://github.com/jgromes/RadioLib)
- [CC1101 Datasheet](https://www.ti.com/product/CC1101)
- [API Documentation](./API_DOCUMENTATION.md)
- [Project README](./README.md)

---

**Автор**: Система Умных Ворот  
**Дата**: 2024  
**Лицензия**: MIT

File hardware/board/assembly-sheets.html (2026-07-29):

# Умные Ворота — листы сборки платы (r3)

Сгенерировано из board.json скриптом gen_sheets.py. Печатать в альбомной ориентации. Разводка однослойная: наложений и общих паек нет, пересечения — только «изолированный провод поверх» (кольца ⨯ на чертеже).

## 1. Нарезка — дорожки (голая лужёная проволока, укладывать ПЕРВЫМИ)

Дорожка пропаивается на каждом пятачке по пути. Длина указана с малым запасом.

№ | Цвет | Тип | Длина | Откуда → куда | Цепь / примечание
1 | | лужёнка 0.5–0.8 мм | 20 мм | STAR.IN → STAR.L_SIM | Земля — звезда — перемычка узла: проволока вдоль ряда
2 | | лужёнка 0.5–0.8 мм | 15 мм | [52,32] → STAR.L_PWR | Земля — звезда — перемычка узла: проволока поперёк
3 | | лужёнка 0.5–0.8 мм | 15 мм | LED1.K → [42,22] | Земля — звезда — катод LED 12 В → луч звезды
4 | | лужёнка 0.5–0.8 мм | 15 мм | [1,31] → Q1.E | Земля силовая (реле) — отвод → эмиттер Q1 (мимо ножек Q2)
5 | | лужёнка 0.5–0.8 мм | 25 мм | U4.OUT- → C1.- | Земля GSM — минус выхода → минус 2200 мкФ, парой с плюсом
6 | | лужёнка 0.5–0.8 мм | 20 мм | [3,15] → R4.2 | Земля GSM — → нижнее плечо делителя
7 | | лужёнка 0.5–0.8 мм | 25 мм | [3,14] → C2.2 | Земля GSM — → 100 нФ
8 | | лужёнка 0.5–0.8 мм | 15 мм | C3.2 → [42,9] | Земля радио — → развязка 100 нФ: от пина C3 к проводу GND_RF в ряду 9
9 | | лужёнка 0.5–0.8 мм | 30 мм | [1,11] → U3.VCC | +4 В (GSM) — → VCC SIM800L по свободному коридору ряда 9
10 | | лужёнка 0.5–0.8 мм | 15 мм | R3.2 → R4.1 | RXD после делителя — → верх нижнего плеча 20 кОм
11 | | лужёнка 0.5–0.8 мм | 15 мм | R1.1 → Q1.B | База Q1
12 | | лужёнка 0.5–0.8 мм | 25 мм | Q1.C → D1.A | Катушка K1 — коллектор Q1 → анод D1
13 | | лужёнка 0.5–0.8 мм | 25 мм | Q2.C → D2.A | Катушка K2 — коллектор Q2 → анод D2
14 | | лужёнка 0.5–0.8 мм | 15 мм | [10,30] → K1.COIL_B | +12 В (после сетевого модуля) — отвод → катушка K1
15 | | лужёнка 0.5–0.8 мм | 15 мм | [10,36] → K2.COIL_B | +12 В (после сетевого модуля) — отвод → катушка K2
16 | | лужёнка 0.5–0.8 мм | 15 мм | R6.2 → LED1.A | LED 12 В (после резистора) — резистор → анод светодиода

## 1а. Нарезка — провода в изоляции

Длина с запасом на спуски к пятачкам, изгибы и зачистку (~15% + 32 мм). Цвет — колонка «Цвет»: у каждой логической цепи свой; жилы 220 В: L коричневый, «закрыть» чёрный, N синий, PE жёлто-зелёный.

№ | Цвет | Тип | Длина | Откуда → куда | Цепь / примечание
1 | | МГШВ 0.75 чёрный | 50 мм | PWR.-V → STAR.IN | Земля — звезда — −V сетевого модуля → вход узла
2 | | МГШВ 0.75 чёрный | 130 мм | STAR.L_BUCK5 → U5.IN- | Земля — звезда — луч по СВОЕМУ ряду 22 → вход понижайки 5 В
3 | | МГШВ 0.75 чёрный | 255 мм | STAR.L_PWR → Q2.E | Земля силовая (реле) — луч звезды по СВОЕМУ ряду 25 к левому краю; у юго-западного угла уходит на колонку 4 — мимо крепёжного отверстия
4 | | МГШВ 0.75 чёрный | 190 мм | STAR.L_SIM → U4.IN- | Земля GSM — луч звезды по СВОЕМУ ряду 18 → минус входа понижайки 4 В
5 | | МГШВ 0.75 чёрный | 65 мм | C1.- → U3.GND | Земля GSM — → GND SIM800L, восточнее конденсатора
6 | | МГШВ 0.75 чёрный | 110 мм | U5.OUT- → U1.GND | Земля логики (пара 5 В) — минус выхода понижайки → GND ESP32 (северный ряд), парой с проводом 5 В; к звезде — через минус входа понижайки
7 | | МГШВ 0.75 чёрный | 65 мм | U1.GND → U2.GND | Земля радио — GND ESP32 (южный ряд) → GND CC1101 (западная колонка): вниз по колонке 40, затем по ряду 9
8 | | МГШВ 0.75 красный | 100 мм | U5.OUT+ → U1.5V | +5 В — OUT+ понижайки 5 В (юго-западный угол) → пин 5V ESP32 (северный ряд, у USB-угла)
9 | | МГШВ 0.75 красный, сдвоить | 85 мм | U4.OUT+ → C1.+ | +4 В (GSM) — OUT+ понижайки (юго-западный угол) → плюс 2200 мкФ, в обход конденсатора слева
10 | | МГШВ 0.75 красный, сдвоить | 60 мм | [4,9] → C2.1 | +4 В (GSM) — → 100 нФ
11 | | МГШВ 0.75 красный | 65 мм | U1.3V3 → C3.1 | +3.3 В — 3V3 ESP32 (восточный конец северного ряда) → развязка
12 | | МГШВ 0.75 красный | 90 мм | [43,2] → U2.VCC | +3.3 В — → VCC CC1101 (восточная колонка разъёма, юго-восточный угол) — по ряду 2 и колонке 51
13 | | МГТФ / AWG30 | 120 мм | U1.IO18 → U2.SCK | SPI SCK — лан ряда 17 → колонка 51: восточнее колонки 51 сигнальных вертикалей нет (антенный фид на [55,8])
14 | | МГТФ / AWG30 | 100 мм | U1.IO19 → U2.MISO | SPI MISO — лан ряда 12 → колонка 44, подход к MISO с запада
15 | | МГТФ / AWG30 | 85 мм | U1.IO23 → U2.MOSI | SPI MOSI
16 | | МГТФ / AWG30 | 150 мм | U1.IO5 → U2.CSN | CC1101 CSN — лан ряда 16 → колонка 46, подход к CSN с запада
17 | | МГТФ / AWG30 | 120 мм | U1.IO4 → U2.GDO0 | CC1101 GDO0 (данные) — лан ряда 14 → подход к GDO0 с запада, под телом модуля
18 | | МГТФ / AWG30 | 135 мм | U1.IO2 → U2.GDO2 | CC1101 GDO2 (клок) — лан ряда 13 → колонка 49 (антенный фидер восточнее не трогаем)
19 | | МГТФ / AWG30 | 140 мм | U1.IO16 → U3.TXD | GSM TXD → IO16 — IO16 → запад коридором ряда 17, TXD модуля
20 | | МГТФ / AWG30 | 120 мм | U1.IO17 → R3.1 | IO17 → 10 кОм — IO17 → верх делителя
21 | | МГТФ / AWG30 | 45 мм | R3.2 → U3.RXD | RXD после делителя — выход делителя → RXD модуля
22 | | МГТФ / AWG30 | 180 мм | U1.IO12 → R1.2 | IO12 → база K1 — IO12 → северный коридор → СВОЯ колонка 13 → резистор базы K1
23 | | МГТФ / AWG30 | 185 мм | U1.IO13 → R2.2 | IO13 → база K2 — IO13 → ряд 2 → СВОЯ колонка 14 → резистор базы K2
24 | | перемычка | 40 мм | R2.1 → Q2.B | База Q2
25 | | МГШВ 0.75 | 45 мм | D1.A → K1.COIL_A | Катушка K1 — → вывод катушки K1
26 | | МГШВ 0.75 | 45 мм | D2.A → K2.COIL_A | Катушка K2 — → вывод катушки K2
27 | | ПуГВ 0.75 коричневый, под платой | 65 мм | K1.NO → ACOUT.OPEN | 220 В: «открыть» к приводу — контакт NO K1 → клемма «открыть»
28 | | ПуГВ 0.75 чёрный, под платой | 65 мм | K2.NO → ACOUT.CLOSE | 220 В: «закрыть» к приводу — контакт NO K2 → рядом 37 → клемма «закрыть»
29 | | ПуГВ 0.75 коричневый, под платой | 60 мм | ACIN.L → FU1.IN | 220 В: фаза до предохранителя — клеммник ввода → восточный вывод держателя предохранителя
30 | | ПуГВ 0.75 синий, под платой | 55 мм | ACIN.N → PWR.AC-N | 220 В: ноль (навесом) — клеммник ввода → сетевой пин AC-N модуля
31 | | ПуГВ 0.75 синий, под платой | 55 мм | ACIN.N → ACOUT.COM | 220 В: ноль (навесом) — → общая клемма привода, рядом 36
32 | | МГШВ 0.75 красный | 100 мм | PWR.+V → U5.IN+ | +12 В (после сетевого модуля) — +V модуля → вниз и по ряду 26 → вход понижайки 5 В
33 | | МГШВ 0.75 красный | 110 мм | [35,26] → [10,26] | +12 В (после сетевого модуля) — магистраль дальше на запад по ряду 26
34 | | МГШВ 0.75 красный | 40 мм | [17,26] → U4.IN+ | +12 В (после сетевого модуля) — отвод → вход понижайки 4 В
35 | | МГШВ 0.75 красный | 50 мм | [10,26] → D1.K | +12 В (после сетевого модуля) — спуск по колонке 11 → катод D1
36 | | МГШВ 0.75 красный | 60 мм | [10,30] → D2.K | +12 В (после сетевого модуля) — дальше вниз → катод D2
37 | | МГШВ 0.75 красный | 50 мм | [48,26] → R6.1 | +12 В (после сетевого модуля) — ветка → резистор LED 12 В
38 | | ПуГВ 0.75 коричневый, под платой | 95 мм | FU1.OUT → PWR.AC-L | 220 В: фаза после предохранителя — выход предохранителя → ряд 31 → сетевой пин AC-L модуля
39 | | ПуГВ 0.75 коричневый, под платой | 40 мм | [20,30] → K1.COM | 220 В: фаза после предохранителя — отвод → COM K1
40 | | ПуГВ 0.75 коричневый, под платой | 50 мм | K1.COM → K2.COM | 220 В: фаза после предохранителя — перемычка COM K1 ↔ COM K2 по колонке 19

## 2. Чертёж НИЗА платы — В ЗЕРКАЛЕ (как видишь перевёрнутую плату у паяльника)

Плата перевёрнута через нижний край: ряд 1 сверху, колонки идут справа налево — цифры линейки совпадают с 3D-вьюером. Серые толстые линии с точками — дорожки-лужёнки; цветные — провода; янтарные кольца — перекрёстки (провод проходит поверх).

## 2а. Верх платы — расстановка компонентов

## 3. Прозвонка после пайки (вилка выдернута, модули НЕ вставлены в гнёзда)

### 3.1 Должно звониться (0 Ом): точки одной цепи

Цепь | Точки — все звонятся между собой
Земля — звезда | U5.IN- [35,19] · STAR.IN [50,33] · STAR.L_BUCK5 [53,33] · STAR.L_SIM [54,33] · STAR.L_PWR [52,34] · PWR.-V [48,36] · LED1.K [42,20]
Земля силовая (реле) | Q1.E [2,31] · Q2.E [2,37]
Земля GSM | U3.GND [8,7] · U4.OUT- [3,19] · R4.2 [7,15] · C1.- [3,13] · C2.2 [9,14]
Земля логики (пара 5 В) | U1.GND [26,3] · U5.OUT- [21,19]
Земля радио | U1.GND [39,12] · U2.GND [46,9] · C3.2 [42,8]
+5 В | U1.5V [21,3] · U5.OUT+ [21,24]
+4 В (GSM) | U3.VCC [4,7] · U4.OUT+ [3,24] · C1.+ [3,11] · C2.1 [9,12]
+3.3 В | U1.3V3 [39,3] · U2.VCC [47,9] · C3.1 [42,6]
SPI SCK | U1.IO18 [31,12] · U2.SCK [46,7]
SPI MISO | U1.IO19 [32,12] · U2.MISO [46,6]
SPI MOSI | U1.IO23 [38,12] · U2.MOSI [47,7]
CC1101 CSN | U1.IO5 [30,12] · U2.CSN [47,8]
CC1101 GDO0 (данные) | U1.IO4 [27,12] · U2.GDO0 [46,8]
CC1101 GDO2 (клок) | U1.IO2 [25,12] · U2.GDO2 [47,6]
GSM TXD → IO16 | U1.IO16 [28,12] · U3.TXD [7,7]
IO17 → 10 кОм | U1.IO17 [29,12] · R3.1 [10,10]
RXD после делителя | U3.RXD [6,7] · R3.2 [7,10] · R4.1 [7,12]
IO12 → база K1 | U1.IO12 [27,3] · R1.2 [7,29]
IO13 → база K2 | U1.IO13 [25,3] · R2.2 [7,35]
База Q1 | Q1.B [2,29] · R1.1 [4,29]
База Q2 | Q2.B [2,35] · R2.1 [4,35]
Катушка K1 | K1.COIL_A [11,28] · Q1.C [2,27] · D1.A [8,27]
Катушка K2 | K2.COIL_A [11,34] · Q2.C [2,33] · D2.A [8,33]
220 В: «открыть» к приводу | K1.NO [15,30] · ACOUT.OPEN [20,35]
220 В: «закрыть» к приводу | K2.NO [15,36] · ACOUT.CLOSE [22,35]
220 В: фаза до предохранителя | ACIN.L [27,35] · FU1.IN [29,29]
220 В: ноль (навесом) | PWR.AC-N [33,32] · ACIN.N [29,35] · ACOUT.COM [24,35]
+12 В (после сетевого модуля) | U4.IN+ [17,24] · U5.IN+ [35,24] · K1.COIL_B [11,30] · K2.COIL_B [11,36] · D1.K [8,30] · D2.K [8,36] · PWR.+V [48,33] · R6.1 [48,20]
220 В: фаза после предохранителя | K1.COM [18,30] · K2.COM [18,36] · PWR.AC-L [33,36] · FU1.OUT [20,29]
LED 12 В (после резистора) | R6.2 [46,20] · LED1.A [44,20]

### 3.2 Обязано быть в обрыве / без КЗ

Щуп 1 | Щуп 2 | Ожидание
ACIN.L | ACIN.N | ∞ — фаза и ноль
ACIN.L | ACIN.PE | ∞
ACIN.N | ACIN.PE | ∞
FU1.OUT | ACOUT.OPEN | ∞ — контакт NO K1 разомкнут без питания
FU1.OUT | ACOUT.CLOSE | ∞ — контакт NO K2 разомкнут
ACOUT.OPEN | ACOUT.CLOSE | ∞
ACIN.L | PWR.+V [48,33] | ∞ — сеть изолирована от 12 В
ACIN.L | узел звезды [52,33] | ∞ — сеть изолирована от земли
ACIN.N | PWR.+V [48,33] | ∞
ACIN.N | узел звезды [52,33] | ∞
PWR.+V [48,33] | узел звезды [52,33] | не КЗ: >1 кОм; короткий писк заряда конденсаторов — норма
U5.OUT+ [21,24] (5 В) | узел звезды [52,33] | не КЗ (входы модулей)
U4.OUT+ [3,24] (4 В) | узел звезды [52,33] | не КЗ
C3.1 [42,6] (3.3 В) | узел звезды [52,33] | не КЗ
PWR.+V [48,33] | U5.OUT+ [21,24] | ∞ / не КЗ — шины разделены понижайкой
PWR.+V [48,33] | U4.OUT+ [3,24] | ∞ / не КЗ
U5.OUT+ [21,24] | C3.1 [42,6] | ∞ / не КЗ

Только после чистой прозвонки подавать 220 В — сначала без модулей, выставить 5.0 и 4.0 В на выходах понижаек (щупы на пайки выходов понижаек U5.OUT+/U4.OUT+ против узла звезды), обесточить, вставить модули.

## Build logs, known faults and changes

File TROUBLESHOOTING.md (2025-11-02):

# 🔧 Устранение неполадок CC1101

## ❌ Ошибка -2: Модуль не найден

Если вы видите:
```
[CC1101] ❌ Ошибка инициализации, код: -2
```

Это означает **RADIOLIB_ERR_CHIP_NOT_FOUND** - ESP32 не может связаться с CC1101 по SPI.

---

## ✅ Пошаговая диагностика:

### Шаг 1: Проверьте питание ⚡

**КРИТИЧНО!** CC1101 работает ТОЛЬКО на 3.3V!

```
✅ Правильно:
   CC1101 VCC → ESP32 3.3V
   CC1101 GND → ESP32 GND

❌ НЕПРАВИЛЬНО:
   CC1101 VCC → ESP32 5V  (ПОВРЕДИТ МОДУЛЬ!)
```

**Как проверить:**
1. Отключите ESP32 от питания
2. Мультиметром проверьте, что VCC подключен к 3.3V пину
3. Проверьте, что GND подключен к GND

---

### Шаг 2: Проверьте SPI подключение 🔌

**Обязательные 4 провода SPI:**

| CC1101 | ESP32 | Проверка |
|---|---|---|
| SCK | GPIO18 | ☐ Проверено |
| MISO | GPIO19 | ☐ Проверено |
| MOSI | GPIO23 | ☐ Проверено |
| CS | GPIO5  | ☐ Проверено |

**Как проверить:**
1. Визуально осмотрите каждый провод
2. Убедитесь, что провода плотно вставлены
3. Попробуйте шевельнуть провода - они не должны выпадать

---

### Шаг 3: Проверьте управляющие пины 📡

| CC1101 | ESP32 | Проверка |
|---|---|---|
| GDO0 | GPIO4  | ☐ Проверено |
| GDO2 | GPIO2  | ☐ Проверено |

**Примечание:** GDO2 можно временно не подключать для теста.

---

### Шаг 4: Проверьте качество контактов 🔍

**Частые проблемы:**
- ❌ Плохой контакт в breadboard
- ❌ Окисленные контакты
- ❌ Перепутаны провода местами
- ❌ Слишком длинные провода (>20 см)

**Решение:**
- ✅ Используйте короткие провода (<15 см)
- ✅ Плотно вставьте все контакты
- ✅ Попробуйте другие отверстия в breadboard

---

### Шаг 5: Проверьте сам модуль CC1101 🔬

**Визуальный осмотр:**
1. На модуле не должно быть:
   - Трещин
   - Сколов
   - Обгоревших компонентов
   - Следов перегрева

2. Проверьте, что чип CC1101 правильно припаян

**Проверка питания:**
Подключите ESP32 и мультиметром измерьте напряжение между VCC и GND на CC1101:
- ✅ Должно быть: 3.3V (±0.1V)
- ❌ Если 0V - проблема с питанием
- ❌ Если 5V - НЕМЕДЛЕННО ОТКЛЮЧИТЕ!

---

### Шаг 6: Тестовая схема (минимальная) 🧪

Попробуйте подключить только обязательные пины:

```
ESP32          CC1101
─────          ──────
3.3V    ────►  VCC
GND     ────►  GND
GPIO18  ────►  SCK
GPIO19  ────►  MISO
GPIO23  ────►  MOSI
GPIO5   ────►  CS
GPIO4   ────►  GDO0
```

**Временно отключите:**
- GDO2 (не критичен)

Если заработает - добавьте GDO2 обратно.

---

### Шаг 7: Попробуйте другие пины CS 🔄

Иногда проблема в конкретном GPIO. Попробуйте изменить пин CS:

#### Вариант A: Используйте GPIO15

Измените в `main.cpp`:
```cpp
#define CC1101_CS   15  // вместо 5
```

#### Вариант B: Используйте GPIO17

Измените в `main.cpp`:
```cpp
#define CC1101_CS   17  // вместо 5
```

Перекомпилируйте и загрузите прошивку:
```bash
pio run --target upload
```

---

## 🧪 Тест SPI шины

Добавьте тестовый код для проверки SPI:

```cpp
// В функции setup() перед CC1101Manager::init()

Serial.println("[TEST] Тест SPI шины...");
SPI.begin(18, 19, 23, 5); // SCK, MISO, MOSI, CS
delay(100);

pinMode(CC1101_CS, OUTPUT);
digitalWrite(CC1101_CS, HIGH);
delay(10);
digitalWrite(CC1101_CS, LOW);
SPI.transfer(0x30); // CC1101 VERSION register
digitalWrite(CC1101_CS, HIGH);

Serial.println("[TEST] SPI команда отправлена");
```

---

## 📊 Коды ошибок RadioLib:

| Код | Значение | Причина |
|-----|---|---|
| -2  | CHIP_NOT_FOUND | Модуль не отвечает по SPI |
| -1  | SPI_WRITE_FAILED | Ошибка записи SPI |
| 0 | OK | Всё работает! ✅ |
| -3  | INVALID_FREQUENCY | Неподдерживаемая частота |

---

## 🆘 Если ничего не помогло:

### 1. Попробуйте другой CC1101 модуль
Возможно, ваш модуль неисправен.

### 2. Проверьте ESP32
Попробуйте подключить другое SPI устройство для проверки.

### 3. Используйте логический анализатор
Проверьте сигналы на линиях SPI.

### 4. Свяжитесь с продавцом
Возможно, модуль был поврежден при транспортировке.

---

## ✅ Контрольный список:

Перед повторной попыткой убедитесь:

- [ ] VCC подключен к 3.3V (НЕ 5V!)
- [ ] GND подключен к GND
- [ ] SCK подключен к GPIO18
- [ ] MISO подключен к GPIO19
- [ ] MOSI подключен к GPIO23
- [ ] CS подключен к GPIO5
- [ ] GDO0 подключен к GPIO4
- [ ] GDO2 подключен к GPIO2
- [ ] Все провода надежно закреплены
- [ ] Провода не длиннее 20 см
- [ ] ESP32 получает стабильное питание
- [ ] На модуле нет видимых повреждений
- [ ] Между VCC и GND на CC1101 ровно 3.3V

---

## 📸 Попросите помощи:

Если проблема не решается, сделайте фото:
1. Общий вид подключения
2. Крупный план CC1101
3. Крупный план подключений к ESP32
4. Текст ошибки в Serial Monitor

И обратитесь на форум с этими фотографиями.

---

## 🎉 Успешная инициализация

Если всё работает, вы увидите:
```
[CC1101] ✅ Инициализация успешна!
[CC1101] Битрейт: 3.79 kbps
[CC1101] Ширина полосы RX: 58 кГц
[OK] CC1101 успешно инициализирован
```

Удачи! 🚀

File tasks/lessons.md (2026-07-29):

# Lessons — самообучение агента

Живой журнал уроков. **Читай в начале каждой сессии. Дописывай после каждой правки/замечания/бага.**

## Как пользоваться
- Перед работой — прочитай весь файл, не повторяй записанные ошибки.
- После любой корректировки от пользователя или найденного бага — добавь запись по шаблону ниже.
- Одна запись = один конкретный паттерн. Формулируй правило так, чтобы оно физически не дало повторить ошибку.

### 2026-06-24 — Flipper CLI: открывать ОДНО соединение, переживать дроп CDC, не передавать неподдерживаемое
- **Что случилось:** HIL-прогон протоколов (Flipper TX → ESP32 RX) дважды ронял Flipper: USB-CDC отваливался (`Errno 6 Device not configured`, потом порт исчезал совсем), прогон падал.
- **Почему:** (1) харнес открывал/закрывал serial-порт Flipper на КАЖДУЮ команду — частый реконнект CDC дестабилизирует USB-стек Flipper; (2) `subghz tx_from_file` для протокола, которого нет в TX-энкодере Flipper, уходит в `Error transmitter` и роняет CDC (иногда визуально ребутит Flipper); (3) старый код добивал мёртвый порт ретраями.
- **Правило:** для скриптов к Flipper CLI — держать **одно постоянное соединение** на весь прогон; TX слать «толерантно» (дроп чтения по USB ≠ провал передачи, радио излучает независимо); ловить `Error transmitter`/`cannot`/`not found` и **не бить по неподдерживаемому протоколу повторно** (early-exit); делать прогон **резюмируемым** (инкрементальный JSON, skip уже сделанного) и устойчивым к пропаданию порта (ждать пере-энумерации, не ретраить мёртвый хэндл). Команда Flipper: `subghz tx <key> <freq> <te> <repeat> <device>` — нужен 5-й арг `device` (0=внутр.).
- **Где:** scratchpad/conformance/hil.py (persistent conn + `_send_tolerant` + `flip_health`), runner.py (resume + early-exit).

### 2026-06-24 — HIL-тест декодеров: верить только реальным захватам, отделять «баг прошивки» от «мой вектор» и от «Flipper не умеет TX»
- **Что случилось:** прогнал 39 протоколов Flipper→прошивка. Много `NODECODE`/`OOK`. Соблазн объявить декодер сломанным.
- **Почему:** три разных причины «провала» легко спутать: (а) у Flipper Unleashed **нет TX-энкодера** для 12 протоколов (`Error transmitter`) — это не про прошивку; (б) **сгенерированный** тест-вектор может быть неканоничным (не та разрядность/структура) → Flipper излучит «не тот» кадр; (в) реальный баг прошивки. Плюс важное: это сравнение «**переизлучение Flipper** → приём», а не «реальный пульт → приём» — тайминги энкодера Flipper могут отличаться.
- **Правило:** надёжные выводы — только по **реально захваченным** `.sub` (в этом проекте на SD: `Zar1`=CAME, `test_nero`=Nero Radio, `1.sub`=KeeLoq/DoorHan). Подтверждённые находки этого прогона: **реальный CAME → `Princeton/0x0`** (мисдекод), **реальный Nero Radio → NODECODE**, **реальный KeeLoq → OK**. По сгенерированным векторам вердикт = «требует канонического вектора», НЕ «баг». Прежде чем чинить декодер — перепроверить реальным пультом (тайминги Flipper-энкодера ≠ пульт). Отчёт: `tasks/protocol-conformance-2026-06-24.md`.
- **Где:** методика HIL-тестов декодеров; CC1101Manager.cpp checkReceived / include/SubGhzDecoder.h.
- **Уточнение по CAME (важно, не повтори вывод «декодер CAME сломан»):** разбор сырого приёма показал,
  что при переизлучении реального CAME прошивка получает **искажённую волну** (TE скачет 746↔1314 мкс,
  переходов 60↔889, подряд `L` = короткие `H` теряются, RSSI −74). Значит корень — **качество RX**, а
  не таблица декодера. Конфиг радио КОРРЕКТЕН: `init()` ставит 20 kbps / 135 kHz / OOK
  (CC1101Manager.cpp:1418–1422); API-значения `3.79/58` — устаревшие дефолты `systemState`
  (main.cpp:811–813), не реальные регистры. Подозреваемые: антенна/уровень сигнала, порог
  `MIN_PULSE_US=200` (onInterrupt, режет короткие фронты при джиттере). Прежде чем трогать декодеры —
  чинить приём и проверять сильным/чистым сигналом.

### 2026-06-24 — Системные находки декодера: нестабильное имя 24-бит, жадный Keeloq, провал ≤12 бит
- **Что случилось:** на прогоне всплыли повторяющиеся паттерны мисдекодинга.
- **Почему:** «первый сматчивший побеждает» + пересекающиеся преамбулы. 24-битный OOK ловится то как CAME, то Princeton, то OOK (код обычно верный, имя — лотерея). Keeloq-декодер матчит чужие роллинг-кадры (Nero Sketch→Keeloq, Hormann→Keeloq×57). Протоколы ≤12 бит (Nice FLO, Holtek HT12X, Ansonic) не берёт никто: GenericOOK требует ≥20 бит, спец-декодеры не срабатывают.
- **Правило:** при правках распознавания — (1) развести CAME/Princeton/GenericOOK по таймингам/преамбуле, чтобы имя 24-бит было стабильным; (2) ужесточить преамбулу Keeloq, чтобы не хватал Nero Sketch/Hormann; (3) для коротких протоколов нужен спец-путь (GenericOOK ≥20 бит их режет). Сравнение ключей по `(протокол+частота)` ненадёжно, пока имя 24-бит нестабильно.
- **Где:** include/SubGhzDecoder.h (порядок декодеров), include/protocols/ProtoKeeloq.h, ProtoCAME/ProtoPrinceton, ProtoGenericOOK.
- Дубли объединяй; устаревшее (исправленный код, неактуальные факты) — удаляй.

### 2026-07-04 — Ревью кода: где реально лежат баги (полный отчёт — tasks/code-review-2026-07-04.md)
- **Что случилось:** многоагентное ревью (9 направлений + адверсариальная верификация) подтвердило 43 находки. Ключевое, что легко забыть между сессиями:
- **Безопасность:** ни один `server.on()` в main.cpp не проверяет auth; `/api/gate/trigger` открывает ворота напрямую, минуя `isKeyMatch`; AP `SmartGate-Config`/`12345678` поднята всегда с литеральным паролем. Это НЕ принятое ограничение — чинить.
- **`isKeyMatch` (main.cpp:462-514) слишком мягкий:** ветка 4 матчит по 12-бит префиксу/суффиксу `bitString` БЕЗ протокола; ветка 3 — по 32-бит `code` без bitLength/протокола. Прежде чем «улучшать распознавание», помни: чужой брелок может открыть ворота уже на этом уровне.
- **`verifyKeySignal()` (main.cpp:519) НЕ вызывается нигде** — радио-путь (main.cpp:1598) дёргает реле сразу после `isKeyMatch`. CLAUDE.md описывает верификацию повторов, которой в реальности нет. Не доверяй CLAUDE.md в этом пункте.
- **`resetReceived()` (CC1101Manager.cpp:1283) гонится с живым ISR** и может навсегда снять GDO0-прерывание (приём умирает до ребута). Доступ к `receivedFlag`/`rawSignalReady`/`rawSignalIndex` из loop() — только под критической секцией.
- **Мёртвые декодеры (порт из Flipper с инверсией фаз state machine):** Nice FLO (ProtoNiceFlo.h:38), Chamberlain (ProtoGateTx.h:187), Holtek HT12X (ProtoBatch3.h:20) — физически не эмитят; Legrand (ProtoBatch2.h:162) теряет половину кодов. Паттерн бага: `FoundStart/CheckDur` проверяет `if(level)` вместо `if(!level)` (или наоборот) — сверять с рабочими соседями (CAME/Princeton/Holtek в ProtoGateTx.h:78) и с reference_receiver.c.
- **`data_2` не читается в checkReceived (CC1101Manager.cpp:887)** → >64-бит протоколы (Nice One, Alutech, KingGates, Somfy Keytis) декодируются с UB-сдвигом и неверным bitString. И `resetAll()` между буферами не вызывается (кросс-буферная «химера»).
- **NVS без проверок:** save/loadSystemState игнорируют `overflowed()`/`DeserializationError`; полный blob пишется на КАЖДУЮ активацию ворот (износ flash); NVS-настройки радио (bitRate/BW) грузятся, но в setup() не применяются (только частота, main.cpp:1269).
- **Правило:** при любой правке распознавания/приёма — сперва свериться с этим отчётом, не «чинить» то, что уже мёртво по другой причине, и не считать `verifyKeySignal`/auth существующими.
- **Где:** tasks/code-review-2026-07-04.md (полный список с номерами строк и сценариями отказа).

### 2026-07-04 — Исправления по ревью: что чинить смело, а что только с железом
- **Что случилось:** попросили «пофиксить всё, кроме безопасности» по отчёту ревью. Часть находок исправлять безопасно, часть — нельзя без эфира/пультов.
- **Правило (чинить смело):** гонки ISR (`resetReceived` = detach→reset→attach), NVS-проверки (`overflowed()`, `DeserializationError`, возврат bool + сообщение в UI), троттлинг записи счётчика (износ флеша), неблокирующий импульс ворот (`GateControl::update()` в loop вместо `delay`), экранирование WS-JSON (`jsonEscape`), применение сохранённых настроек радио в `setup()` + миграция устаревших 3.79/58→20/135, арифметика TE в уже работающем декодере (Princeton `teSum/bits`). Всё это собралось (`platformio run` SUCCESS) без изменения поведения для рабочих протоколов.
- **Правило (НЕ трогать без железа):** (1) ужесточать `isKeyMatch`/включать `verifyKeySignal` — сломает узнавание реальных CAME/Nero/Keeloq из-за нестабильного имени 24-бит; (2) «оживлять» мёртвые декодеры (Nice FLO/HT12X/Legrand) — риск ложных срабатываний, а Nice FLO стоит 4-м в цепочке и затенил бы Nero/Keeloq; (3) Chamberlain вообще не принимается (преамбула 39 мс > `MAX_PULSE_US=30000` в ISR); (4) `resetAll()` между буферами убьёт межбуферный приём Nero. Вывод: dead-декодер безопаснее, чем неверно оживлённый. Проверять контролируемым TX Flipper по одному протоколу.
- **Где:** tasks/code-review-2026-07-04.md (раздел «✅ Исправлено»), src/CC1101Manager.cpp, src/main.cpp, src/GateControl.cpp, include/protocols/ProtoPrinceton.h.

### 2026-07-08 — Цоколёвки компонентов давать только по даташиту
- **Что случилось:** в инструкции по сборке реле указал ножки BC337 наоборот (левая=эмиттер), по памяти.
- **Почему:** у TO-92 транзисторов нет единого стандарта: BC337/BC547 = C-B-E, а 2N2222/PN2222 = E-B-C (плоской стороной к себе). Понадеялся на «типичную» раскладку.
- **Правило:** любые цоколёвки (транзисторы, стабилизаторы, диодные сборки) в советах по железу — только после сверки с даташитом конкретного компонента, с указанием ориентации корпуса. Особо коварная пара: BC337 (C-B-E) против 2N2222 (E-B-C).
- **Где:** консультации по схемотехнике проекта.
- **Уточнение 2026-07-28 (то же правило — в 3D-модели раскладки):** в board.json реле и модули рисовал «по памяти»: у HF46F контакты поставил парой у торца, а по даташиту они разнесены ВДОЛЬ корпуса (катушечный ряд → 11.5 мм → COM → 7 мм → NO, диагональю по ширине); у модулей LM2596 пятачки — по углам платы: вход парой на одном торце, выход на другом, плюсы на одном длинном крае. Пользователь поймал оба раза по даташиту/фото. Правило: геометрию выводов в модели раскладки задавать только по чертежу даташита конкретного корпуса; если чертежа нет под рукой — ставить fit:verify и писать в note, что раскладка ножек не проверена.

### 2026-07-12 — Отладка железа по Serial: один процесс на порт, мусор в логе ≠ мусор от модуля
- **Что случилось:** при живой отладке SIM800L (1) несколько фоновых python-захватов Serial дрались за /dev/cu.usbserial → «device reports readiness to read but returned no data», потеря кусков лога; (2) сплошной мусор в основном логе оказался НЕ шумом UART2 модуля, а конфликтом на UART0: сигнальный провод модуля был воткнут в пины TX/RX (GPIO1/3, канал USB-лога) вместо TX2/RX2 (GPIO17/16).
- **Почему:** (1) старые nohup-захваты не убивались перед запуском новых; (2) на шелкографии DevKit «TX/RX» и «TX2/RX2» легко перепутать, а симптомы (мусор в логе) выглядят как проблема удалённого устройства.
- **Правило:** (1) перед новым захватом Serial — `pkill` старых; захват всегда один, с авто-reconnect; (2) если основной лог платы замусорен/строки рвутся — сперва подозревать физический конфликт на GPIO1/3 (USB-UART), диагностика: вытащить чужие провода → лог мгновенно чистый; (3) выводы для пользователя писать по подписям шелкографии («пин RX2»), а не только «GPIO16».
- **Где:** методика HIL-отладки; GSMManager (фильтр шума isMostlyPrintable + сводка «Шум на линии» уже в коде).

### 2026-07-23 — Приём мёртв после boot: setBitRate/setRxBandwidth/setFrequencyDeviation выбивают CC1101 из RX
- **Что случилось:** пользователь не мог записать новый ключ с Флиппера — в режиме обучения вообще ничего не приходило. Serial-лог: за все окно обучения НИ ОДНОЙ строки `[CC1101] Буфер: N импульсов` (она печатается для любого сигнала, дошедшего до декодеров). То есть импульсы с GDO0 не набирались — приём был отключён на уровне железа, хотя RSSI читался (SPI жив).
- **Почему:** в `setup()` (main.cpp:1490-1492) после `init()`+`setFrequency()` вызываются `setBitRate/setRxBandwidth/setFrequencyDeviation`. Внутри RadioLib каждый из этих сеттеров шлёт `CMD_IDLE` (`SPIsendCommand(RADIOLIB_CC1101_CMD_IDLE)` — CC1101.cpp:457/477/525), выбивая чип из direct-RX. Обёртки в CC1101Manager возвращали `true` БЕЗ повторного `enterRawReceive()`. Итог: чип оставался в IDLE после boot, приём был мёртв до любой ручной смены частоты (`setFrequency` единственный переармливал RX). Регресс приехал с коммитом «применение сохранённых настроек радио в setup()» (ревью 2026-07-04): раньше эти сеттеры в boot не звались, RX оставался вооружён из `init()`.
- **Правило:** ЛЮБАЯ обёртка над RadioLib-сеттером, меняющим регистры модема (bitRate, RxBW, deviation, freq, mod), ОБЯЗАНА заканчиваться `return enterRawReceive();` — RadioLib гарантированно уводит чип в IDLE. Признак этого класса бага в логе: RSSI читается (SPI ок), но `[CC1101] Буфер:` не появляется вообще ни для какого сигнала. Проверять приём после boot реальным TX, а не только сборкой.
- **Где:** src/CC1101Manager.cpp setBitRate/setRxBandwidth/setFrequencyDeviation (добавлен `enterRawReceive()`); RadioLib CC1101.cpp:457/477/525. Подтверждено HIL: Keeloq (1.sub) декодируется, обучение через `/api/keys/learn` добавляет ключ (keyCount 1→2).

### 2026-07-23 — CC1101 OOK шумит без AGC-пресета; провал декода бывает физическим (позиция), не в коде
- **Что случилось:** после починки мёртвого RX (см. запись выше) реальные брелоки/переизлучение Флиппера декодировались нестабильно — то `Nice FlorS`/`Keeloq` распознаётся, то только `RAW/Unknown`. В UI «3 RAW/Unknown и всё».
- **Почему (2 независимые причины, не путать):**
  1. **Шумовой флуд OOK.** RadioLib `config()` НЕ трогает регистры AGC → остаются сбросовые дефолты (`AGCCTRL2=0x03`, MAIN_TARGET 24 dB). В async-OOK приёмник задирает усиление в паузах и слайсит собственный шум как «сигнал». Замер: **114 ложных RAW-буферов за 8 с БЕЗ передачи**, `RSSI`-гейт бесполезен (в direct-режиме `getRSSI()` всегда читает регистр RSSI = 0 → константа −74 dBm во всех логах). Фикс: наложить AGC-пресет Flipper OOK650 (`FIFOTHR=0x07` ADC_RETENTION, `AGCCTRL2=0x07` MAGN_TARGET 42 dB, `AGCCTRL1=0x00`, `AGCCTRL0=0x91`) в `configureForRawMode()`. Шум упал 114→**20** буферов. BW/битрейт НЕ трогали (20/135 настроены под декодеры). Запись регистров — через существующий субкласс `CC1101Ex::writeReg` (RadioLib прячет `SPIsetRegValue`/`getMod()` в protected).
  2. **Физика приёма (доминирует над кодом).** A/B доказал: в один момент (03:30) все 4 протокола (Keeloq/Nice FloR-S/Nero/CAME) декодировались, через ~9 мин на ТОЙ ЖЕ прошивке — 0 декодов, только RAW; ребут не помогает; сборка БЕЗ AGC даёт ровно тот же ноль. Значит провал декода — **не регресс кода и не AGC**, а положение/ориентация Флиппера относительно антенны (OOK крайне чувствителен) + искажение волны при переизлучении Флиппера (TE-джиттер, длинные ~900 мкс отрезки в буфере).
- **Правило:** (1) прежде чем «чинить декодер» из-за RAW/Unknown — сверить, воспроизводится ли провал при СТАБИЛЬНОМ сильном сигнале; менять положение/дистанцию Флиппера, декод чувствителен к этому сильнее, чем к коду. (2) AGC-пресет обязателен для вменяемого OOK-приёма — без него UI/CPU захлёбываются ложными RAW. (3) `getRSSI()` в direct-режиме врёт (всегда −74) — RSSI-гейт и RSSI-качество в `verifyKeySignal` фактически не работают; не полагаться на них. (4) Переизлучение Флиппера ≠ реальный пульт по таймингам — финальную проверку декода делать реальным брелоком.
- **Где:** src/CC1101Manager.cpp configureForRawMode (AGC-блок), класс CC1101Ex; furi_hal_subghz_configs.h (значения пресета); связано с записью «RX мёртв после boot».

### 2026-07-23 — Zar1/CAME → Princeton/0x0: цепочка причин и что реально исправлено
- **Что случилось:** реальный CAME (Zar1.sub, 24 бит) на чистом сигнале стабильно (10/10) декодируется как `Princeton, 24 бит, код 0x0` и выбрасывается фильтром «код = 0». На Флиппере тот же ключ пишется штатно.
- **Почему (цепочка):** (1) сырой кадр CAME приходит с TE short≈330 / long≈625–660 мкс, НО с артефактами уровня: спайк <40 мкс дробил один LOW на два (`540L 310L`), плюс расколотые биты; (2) остаточный шум набивает буфер до 1023 и **фрагментирует кадр** — преамбула CAME (~18 мс LOW) попадает в один буфер, данные в другой; (3) наш `ProtoCAME` при любом отклонении делает полный `Reset` и снова ждёт преамбулу в ТОМ ЖЕ буфере → не собирается; (4) `ProtoPrinceton` преамбулы не требует, дотягивает 24 бита, но по чужой структуре даёт 0 → фильтр «код=0». Флиппер берёт, потому что у него чистый OOK-приём (кадр не дроблён) + устойчивый декодер.
- **Что исправлено и проверено:** фикс ISR-склейки — при склейке спайка ставим `pendingGlueMerge`, продолжение импульса того же уровня сливаем в ту же запись (убирает `540L 310L`). Не сломал KeeLoq (5–6/6) и Nice FloR-S (4/6). НО CAME сам по себе это не починило.
- **Что НЕ доделано (и почему):** корневой фикс CAME (устойчивость к фрагментации/глитчам, чтобы победить раньше Princeton) требует СТАБИЛЬНОГО чистого сигнала для верификации, а на этом стенде приём физически интермиттентный (в 03:55 кадр чистый → Princeton/0; в 04:06 тот же Zar1 → сплошной мусор ~850L). Непроверяемые правки декодера не вносил. Проверять — сильным стабильным сигналом (реальный пульт/лучше антенна), затем: (а) ужесточить/убрать Princeton для не-Princeton структур; (б) дать ProtoCAME переживать межбуферную фрагментацию; (в) не резать «код=0» до попытки CAME.
- **Что пробовал и откатил:** BW 135→650 кГц (паритет с Flipper OOK650) — на CAME НЕ повлияло (6/6 Princeton/0), KeeLoq/Nice без изменений → откатил к 135, чтобы не отходить от настроенного значения без выгоды.
- **Где:** src/CC1101Manager.cpp onInterrupt (pendingGlueMerge), include/protocols/ProtoCAME.h, ProtoPrinceton.h, порядок в include/SubGhzDecoder.h.

### 2026-07-28 — 3D-раскладка: провода не летают в пятачки сверху, клеммники кормятся с торца
- **Что случилось:** во вьюере платы силовые жилы 220 В опускались на пятачки вертикально сквозь корпуса клеммников/реле/держателя предохранителя, кабель к приводу был нарисован одной жилой вместо трёх, а клеммник привода стоял в глубине платы, куда внешний кабель не подвести.
- **Почему:** маршрут рисовался «пятачок → дуга → пятачок» без учёта того, что пятачок сидит ПОД корпусом детали, а у винтовых клеммников (KF301) вход провода — на торце, и внешний кабель физически заходит горизонтально. Кабель моделировался одной линией «клеммник→узел», хотя в нём три жилы на три зажима.
- **Правило:** (1) у любой детали с корпусом жила к её пятачку подводится сбоку, через «выход» за ближайшей свободной гранью (viewer.js chooseWrap), а не вертикально сверху; (2) многожильный кабель в данных — отдельная связь на каждую жилу с назначением на конкретный зажим (fromPin/toPin) и цветом проводника (L корич., L2 чёрн., N син.); (3) клеммники ставить зажимами к краю платы/стенке, от которой приходит кабель — иначе торцевой вход недостижим; (4) согласовывать раскладку с case.scad (позиции и роли гермовводов), а не выдумывать положение узлов корпуса.
- **Где:** hardware/board/board.json (ACOUT/FU1/enclosure), viewer.js (chooseWrap, terminalEntry, drawEncLink), case.scad (gland_out_x/gland_in_x).
- **Уточнение (та же сессия, два захода):** «красиво прижатые» жилы стали нечитаемы — спрятались за корпусами; рентген-след (полупрозрачный дубль с depthTest:false) помог лишь частично. Итоговое решение — как у нижней разводки: жилам нужно СВОБОДНОЕ пространство. Перемычки 220 подняты в видимый жгут над островком (взлёт сбоку от корпуса → пролёт выше корпусов → спуск сбоку к пятачку), след оставлен как страховка. Правило: разводка читаема, когда провода идут в пустоте, а не в щелях между деталями. ФИНАЛ (решение пользователя): вся разводка, включая 220 В, — ПОД платой; сверху только корпуса; сеть 220 не выходит из островка 220. Не изобретать «навесной» монтаж без запроса — сначала спросить, где пользователь хочет видеть провода. Отдельное правило: у снаббер-диода ветку +12 В вести с ножки катушки, а не отдельным отводом магистрали — иначе на рендере «питание приходит к реле дважды».

### 2026-07-28 — Многоагентное ревью раскладки: что оно поймало (не повторять эти классы ошибок)
- **Что случилось:** полное ревью board.json (79 агентов, каждый вывод — 2 независимых скептика с первоисточниками) нашло 23 реальные ошибки, большинство — «модель по памяти» вместо «модель по даташиту».
- **Классы ошибок, которые ловить ДО пользователя:** (1) гребёнки/ряды модулей зеркально перепутаны (ESP32: силовой ряд — северный при USB влево; SIM800L: порядок пинов зависит от ориентации холдера); (2) корпус взят от соседней серии (IRM-10 — это 45.7×25.4×21.5, а не 33.7×22.2 от IRM-01/03); (3) пинауты выдуманы симметричными, а в реальности асимметричны (IRM-10: L и −V у одного края); (4) выводы компонентов «по интуиции» вместо чертежа (HF46F: три вывода в линию + один одиночный); (5) маршруты сквозь занятые отверстия (Q2, гребёнка SIM, соседние пины CC1101) — нужен скрипт-чек «сегмент сквозь чужой пин»; (6) декларации в доках расходятся с геометрией (зазор 12.7 мм был невыполним — честно посчитать и переписать).
- **Правило:** после любой правки раскладки гонять не только validate.py, но и проверку сквозных проходов (gcd-шаг по сегментам против словаря пиновых отверстий); заявленные в доках зазоры пересчитывать по фактическим координатам. Скептикам давать текущий файл: они сверяют с git HEAD и рабочей копией и явно помечают устаревшие находки.
- **Где:** tasks/todo.md (полный список применённого), выводы workflow wf_c0f2b67d-ec8.

## Шаблон записи
```
### YYYY-MM-DD — <короткое название>
- **Что случилось:** <ошибка / замечание>
- **Почему:** <корневая причина>
- **Правило:** <что делать в будущем, чтобы не повторить>
- **Где:** <файл/модуль/область, если применимо>
```

---

## Уроки

### 2026-06-23 — Граф знаний строим без артефактов сборки
- **Что случилось:** при первом построении графа минифицированный React-бандл (`data/static/js/main.*.js`) добавил ~310 мусорных узлов (`aa()`, `bc()`…) и ~10 бессмысленных сообществ.
- **Почему:** `detect` цепляет собранный `.js` как код.
- **Правило:** перед кластеризацией исключать узлы из `data/static/` и `*/build/*`; в граф идут только исходники (`src/`, `include/`, `smart-gate-frontend/src/`, docs).
- **Где:** graphify pipeline.

### 2026-06-23 — Перед коммитом проверяй remote: локальная ветка может сильно отставать
- **Что случилось:** запушил доки, push отклонён — на `origin/main` оказался крупный пласт работы (40 Flipper-декодеров, новый фронт, partitions.csv), которого не было локально. При rebase — конфликт в `main.cpp`; мой старый локальный фикс (RSSI-фильтр `-70`) пришлось откатить, т.к. он был поверх устаревшего файла.
- **Почему:** документировал и правил код по устаревшему локальному snapshot, не сделав `git fetch` в начале.
- **Правило:** в начале сессии — `git fetch && git log --oneline HEAD..origin/main`. Если remote впереди — сперва подтянуть, потом анализировать/документировать. Граф знаний и CLAUDE.md строить только по актуальному коду.
- **Где:** git workflow.

### 2026-06-23 — Активный декодер — SubGhzMultiDecoder, а не ALL_PROTOCOLS[]
- **Что случилось:** легко перепутать две системы декодирования в репозитории.
- **Почему:** старый `SubGhzProtocols.cpp` (`ALL_PROTOCOLS[]`) и `tryDecodeKnownProtocols()` остались в коде, но в реальном пути приёма не вызываются.
- **Правило:** путь декодирования = `CC1101Manager::checkReceived()` → `multiDecoder.feed()` (state-machine декодеры из `include/protocols/`). Менять распознавание протоколов — там, а не в legacy-конфигах.
- **Где:** CC1101Manager.cpp ~877, include/SubGhzDecoder.h.

### 2026-06-23 — Граф обновляем через update-graph.sh, не через `graphify hook`
- **Что случилось:** встроенный `graphify hook` после каждого коммита пересобирал граф БЕЗ исключения путей — заново тянул `graphify-out/` (само-скан), `data/static/` минифицированный JS и возвращал ненужный `graph.html`.
- **Почему:** у штатного hook нет фильтра путей; кэш накапливает и артефакты сборки.
- **Правило:** для обновления графа использовать `./update-graph.sh` (исключает `graphify-out/`, `.claude/`, `data/static/`, `*.min.js`, не делает html). Он повешен на `.git/hooks/post-commit` (срабатывает только при изменении кода; docs — вручную `/graphify . --update --obsidian`). Hook локальный, не в репозитории — при свежем клоне переустановить.
- **Где:** update-graph.sh, .git/hooks/post-commit.

### 2026-06-23 — README устарел, источник правды — CLAUDE.md + src/
- **Что случилось:** README описывает RF433/SRX882, дисплей ST7789 и джойстик, которых в коде нет (сейчас CC1101 + веб-интерфейс).
- **Почему:** README не обновляли при переходе на CC1101.
- **Правило:** факты об архитектуре брать из CLAUDE.md / графа знаний / `src/`, а не из README. При расхождении — верить коду.
- **Где:** README.md vs src/.

### 2026-07-28 — Повторная команда воротам: пошаговая логика, а не игнор
- **Что случилось:** во время открытия повторная команда игнорировалась — ворота нельзя было остановить/закрыть, пока фаза не отработает до конца.
- **Почему:** машина состояний GateControl трактовала повторный сигнал асимметрично (в OPENING — пропуск, в CLOSING — сразу реверс), «стопа» как состояния не существовало.
- **Правило:** любой триггер (веб/брелок/GSM) — это одна «кнопка» с пошаговой логикой привода: покой→открытие, движение→стоп (фаза STOPPED), стоп→движение в обратную сторону через REVERSE_PAUSE 500 мс, пауза «открыто»→закрытие. Поведение проверять живым прогоном по serial-логу (5 переходов), а не только сборкой.
- **Где:** src/GateControl.cpp (enum Phase, startCycle), include/GateControl.h.

### 2026-07-28 — OTA: миграция разделов с переносом NVS через esptool
- **Что случилось:** для OTA нужен второй app-слот, а перекройка partitions.csv двигает userdata — наивная перепрошивка стёрла бы ключи/телефоны.
- **Почему:** NVS-раздел привязан к смещению во флеше; при смене таблицы данные по старому адресу становятся невидимы.
- **Правило:** перед сменой таблицы разделов — `esptool read_flash <старый offset> <size>` в бэкап, после прошивки — `write_flash <новый offset>`; NVS-блоб позиционно-независим и переносится как есть. esptool на 460800 бод через CP2102 даёт «Invalid head of packet» — использовать 115200. Проверка миграции — по boot-логу («Состояние системы загружено: N телефонов, M ключей»), не по отсутствию ошибок.
- **Где:** partitions.csv, make-ota.sh, /api/ota/* в main.cpp.

## 2026-07-30 — посадочные места сверять с фактическим экземпляром, а не с типовым модулем
- **Что случилось:** ESP32 в модели сидел в рядах 5/15 (кол. 22–40), фактический встал D21–N39
  (ряды 4/14, кол. 21–39) — на отверстие выше и левее. CC1101 в модели был «два столбца пинов
  вдоль края» с цоколёвкой VCC/CSN/MISO/GDO0 в западной колонке, а реальный модуль D-SUN 27×15
  имеет разъём 2×4 с совсем другой раскладкой (нечётные пины — ряд GND, чётные — ряд VCC).
- **Почему:** «типовая» посадка из головы/чужих фото ≠ конкретный экземпляр; у клонов гуляют
  и межрядное расстояние, и порядок пинов.
- **Правило:** перед разводкой каждого модуля запрашивать у пользователя фактические углы посадки
  в заводских координатах платы (буква+номер) и фото цоколёвки; помечать `fit:"verify"` до
  подтверждения и снимать флаг только после сверки с железом. При переносе цоколёвки с фото
  «вид снизу» → «вид сверху» обязательно зеркалить и проговаривать ориентацию (куда смотрит SMA/USB).
- **Дополнение (та же дата):** пользователь дважды повторил «плата уже» — а я дважды отвечал про
  шаг пинов. Он говорил про НАРИСОВАННЫЙ КОРПУС (30.5 мм в модели против 27 мм по факту).
  Правило: у модуля два независимых габарита — сетка пинов и физический корпус; сверять и
  фиксировать в board.json оба (корпус можно дробными координатами).
- **Финал истории с ESP32:** модуль оказался узким клоном — межрядное 22.86 мм (0.9"),
  а не 25.4. Я дважды ответил «ширина стандартная», считая шаг по буквам углов, хотя
  пользователь трижды сказал «плата уже». Надёжный вопрос — не «какие буквы у углов»
  (шелкография может пропускать I/O), а «сколько СВОБОДНЫХ рядов между гребёнками»:
  физический счёт дырок бьёт чтение букв. 8 свободных рядов = 9 шагов = 22.86 мм.

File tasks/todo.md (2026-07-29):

# План 3: Редизайн веб-панели (ui-ux-pro-max)

## Задача
Сделать панель максимально красивой и удобной. Только представление/UX —
вся логика API, WebSocket, блокировок и черновиков инпутов сохраняется как есть
(она выверена, см. lessons). Устройство офлайн (AP 192.168.4.1) — никаких CDN/веб-шрифтов.

## Дизайн-решения (по скиллу ui-ux-pro-max)
- Стиль: тёмная OLED-панель «операционного» типа, статусные цвета (зелёный/янтарный/красный),
  плотная, но сканируемая. Системные шрифты + mono для данных.
- Адаптив: мобайл — нижняя навигация; ≥900px — сайдбар слева (правило adaptive-navigation).
- Иконки: единый набор inline-SVG (стиль Lucide, stroke 2) вместо CSS-масок; без эмодзи.
- Главная: hero-карточка ворот с анимированной створкой (тайминги = реальные из настроек),
  статус-пилюля, большая кнопка; карточки-ссылки с иконками; системная строка; журнал с иконками типов.
- Ключи: сегментные пресеты частоты, protocol-badge с детерминированным цветом (hash→hue),
  иконки-кнопки (переименовать/удалить) с aria-label, спектрограмма в цветах токенов.
- Телефоны: форматирование номера (+7 900 123-45-67), вместо пары немаркированных
  тумблеров — кнопки-чипы «SMS»/«Звонок» с иконками (индикатор = контрол).
- WiFi: карточка текущего подключения (wifiInfo из контекста), иконка уровня сигнала,
  замок для защищённых, show/hide пароля.
- Настройки: степперы ±, единицы измерения в поле, липкая панель «Сохранить» при изменениях.
- A11y: focus-visible, aria-label на иконках, prefers-reduced-motion, контраст ≥4.5:1,
  тач-таргеты ≥44px.

## Чеклист
- [x] tasks/todo.md — план (этот)
- [x] src/Icons.tsx — набор SVG-иконок
- [x] src/App.css — новая дизайн-система (токены, layout, сайдбар/нижняя навигация, компоненты)
- [x] src/App.tsx — hero ворот, карточки, журнал, тосты с типами, wifiInfo в контекст
- [x] pages/KeyPage.tsx — рестайл (частота, обучение, список ключей)
- [x] pages/PhonePage.tsx — рестайл (формат номера, чипы SMS/Звонок)
- [x] pages/WiFiPage.tsx — рестайл (текущая сеть, уровни сигнала, пароль)
- [x] pages/SettingsPage.tsx — рестайл (степперы, единицы, липкий сейвбар)
- [x] public/index.html — theme-color
- [x] Сборка `npm run build` без ошибок (72.45 kB JS gzip, 5.95 kB CSS gzip)
- [x] Верификация в браузере (375px и 1280px, скриншоты; API мокался fetch-override)
- [x] Ревью-секция в todo.md

## Ревью (план 3)
- Логика не менялась: все apiCall/WS-подписки, блокировка параллельных WiFi-подключений,
  черновики числовых инпутов (SettingRow), дедуп телефонов — сохранены байт-в-байт по смыслу.
- Новое в контексте App: `wifiInfo`/`wifiStatus` (для карточки текущей сети на странице WiFi),
  тосты получили тип (success/error/info) с иконкой.
- Анимация створки ворот на главной использует реальные тайминги `gateTimings`
  (transition-duration = openDuration/closeDuration) — синхронна с циклом прошивки.
- PhonePage: state хранит только цифры (как раньше), форматирование — чисто визуальное
  (`formatDigits`); maxLength поднят до 13 под маску «900 123-45-67».
- Верифицировано в браузере на 375px и 1280px: все 5 страниц без горизонтального скролла,
  модалки/степперы/сейвбар/чип-тумблеры/анимация ворот работают, консоль без ошибок.
  Устройства в сети не было — API мокался через fetch-override, WS-события (rssi-спектрограмма
  в обучении) на живом железе не проверялись.
- `data/` пересобран и синхронизирован (284 KB из 640 KB SPIFFS). Заливка — `./upload.sh`.
- Контраст: --text-muted поднят до #7d85a1 (≥4.5:1 на --surface); focus-visible,
  aria-label на всех иконках-кнопках, prefers-reduced-motion учтён.

---

# План 2: NeoRelay2 — двухканальное управление воротами (открыть/закрыть)

## Задача
Ворота: 3 провода (общий минус + плюс «открыть» + плюс «закрыть»). NeoRelay2 в режиме
прямого управления (входы J1: 3–5 В): GPIO12 → IN1 (открыть), GPIO13 → IN2 (закрыть).
Прошивка ведёт полный цикл: держать канал 1 «время открытия» → пауза «открыто» →
держать канал 2 «время закрытия». Тайминги — со страницы настроек (сейчас они в
localStorage и крутят только анимацию), сохраняются в userdata NVS.

## Решения
- Режим NeoRelay2 — «кнопка» (K1/K2), реле замкнуто пока активен вход; вся логика
  времени в ESP32. WS2812-режим не используем.
- GateControl: state machine IDLE→OPENING→WAITING→CLOSING(+REVERSE_PAUSE 500 мс
  при перезапуске из фазы закрытия — реверс мотора без мёртвой паузы вреден).
  Interlock: оба канала никогда не активны одновременно.
- Повторный сигнал: в OPENING — игнор, в WAITING — продлить «открыто»,
  в CLOSING — стоп закрытия, пауза, снова открытие.
- Новый API GET/POST `/api/gate/config` {openDuration, stayOpen, closeDuration} (сек);
  фронт грузит тайминги из прошивки, сохраняет кнопкой «Сохранить».

## Чеклист
- [x] GateControl.h/.cpp: два пина + state machine цикла
- [x] main.cpp: GATE_OPEN_PIN/GATE_CLOSE_PIN, тайминги в SystemState+NVS,
      /api/gate/config, все триггеры (радио/GSM/API) → startGateCycle()
- [x] Фронт: App.tsx грузит тайминги из API; SettingsPage сохраняет через API
- [x] Сборка прошивки (SUCCESS, RAM 17.9%/Flash 58.6%) + сборка фронта (tsc чисто)
- [x] CLAUDE.md, граф, схема подключения

## Итерация по железу (2026-07-05)
- NeoRelay2 отменён: вместо него 2× голых реле HF46F-G/5-HS1T (катушка 5 В ~40 мА,
  контакты 7 А/250 В). Катушки — через NPN-ключи (BC337 + 1 кОм в базу + 1N4007
  параллельно катушке), т.к. GPIO не тянет катушку напрямую. Логика активный-высокий,
  прошивка не менялась (те же GPIO12/13).
- Питание всей системы от 220 В на объекте: AC-DC 5 В ≥ 3 А (MEAN WELL RS-15-5 /
  HLK-20M05) → ESP32 VIN + катушки реле + MP1584 (4,0 В → SIM800L).

## Стендовая проверка (2026-07-12) — ПРОЙДЕНА
- Собрано на макетке: ESP32 (USB) + CC1101 + SIM800L (buck 4,0 В от ToolkitRC 12 В,
  1000 мкФ у модуля) + светодиоды на GPIO12/13 через BC337 (имитация реле).
- Проверено вживую: звонок с номера из белого списка → +CLIP → ATH → полный цикл
  «открытие 3 с → открыто 15 с → закрытие 3 с» на светодиодах. SMS от чужого
  (сервисного) номера корректно отклонено. Плата в домашней сети (192.168.0.68).
- Доработки прошивки по итогам отладки: перебор скоростей UART при поиске модуля
  (9600/115200/57600/38400/19200), сброс безномерных звонков по таймауту 8 с,
  фильтр мусора на линии (сводка вместо построчной печати), троттлинг печати
  WS-кадров.
- Осталось: SMS-тест с доверенного номера; пайка на протоплату (реле HF46F-G +
  обвязка); боевое питание RS-15-12; декодирование UCS2 в журнале (косметика).

## Ревью (план 2)
- Прошивка теперь сама ведёт цикл открыть→открыто→закрыть; анимация на фронте
  осталась клиентской (совпадает по таймингам). WS-событие фаз — возможное улучшение.
- Повторный триггер в фазе закрытия делает реверс через мёртвую паузу 500 мс.
- На железе не проверено; NeoRelay2 перевести в режим «кнопка», активный уровень —
  высокий (микропереключатели K1/K2).

---

# План 1 (сделано): поддержка SIM800L — открытие ворот по звонку/SMS

## Задача
По входящему звонку или SMS с номера из белого списка (страница «Телефоны» в веб-UI)
подавать импульс на ворота. Микрофон/динамик/DTR не используются — только UART.

## Ключевые решения (дизайн)
- **Белый список — единый:** `systemState.phones` (уже есть UI, API `/api/phones`, поля
  `smsEnabled`/`callEnabled`, хранение в `userdata` NVS). Собственный NVS-список из
  заглушки GSMManager удаляем — это дублирование.
- **Связь модулей:** GSMManager не знает о `systemState` — main.cpp передаёт два колбэка:
  `trustedCheck(number, isCall)` (проверка по списку с учётом флагов) и
  `gateOpen(source)` (импульс + счётчик + логи, как в радио-пути).
- **Протокол:** сырые AT-команды по UART2 (Serial2, RX=16, TX=17, 9600).
  TinyGSM не используем — для RING/+CLIP/+CMT достаточно построчного парсера,
  прозрачнее для отладки.
- **Неблокирующая инициализация:** state machine (PROBE → CONFIG → READY) внутри
  `handleGSM()`; при отсутствии модуля — повторная проба каждые 10 с, loop() не
  блокируется (важно: блокировки loop() роняют приём радио).
- **Конфигурация SIM800L:** `ATE0`, `AT+CLIP=1` (АОН), `AT+CMGF=1` (SMS text),
  `AT+CNMI=2,2,0,0,0` (SMS сразу в UART, не копится на SIM).
- **Звонок:** `+CLIP:` → номер; доверенный (callEnabled) → `ATH` (сброс) + ворота;
  чужой → `ATH` + warning в лог. Дедуп повторных +CLIP одного звонка (10 с).
- **SMS:** `+CMT:` → отправитель; доверенный (smsEnabled) → ворота (текст SMS не
  проверяем — любое SMS с доверенного номера открывает). Чужие — warning.
- **Сравнение номеров:** только цифры, по последним 10 цифрам (+7/8/7-форматы дают
  одинаковый хвост).

## Чеклист
- [x] Переписать `include/GSMManager.h` — новый интерфейс (init с колбэками, isReady)
- [x] Переписать `src/GSMManager.cpp` — UART2, state machine, парсер +CLIP/+CMT
- [x] main.cpp: колбэки `gsmTrustedCheck`/`gsmGateOpen` (зеркалят радио-путь:
      triggerGatePulse + gateOpenCount + persistGateCountThrottled + RingLog + sendLog)
- [x] main.cpp: `GSMManager::init(...)` в setup(), `GSMManager::handleGSM()` в loop()
- [x] Сборка `platformio run` — SUCCESS (RAM 17.9%, Flash 58.4%)
- [x] Обновить CLAUDE.md (GSM больше не заглушка) и граф (`./update-graph.sh`)
- [x] Схема подключения SIM800L для пользователя (питание 4В/2А, делитель на RXD)

## Ревью
- Заглушка GSMManager (свой NVS-список номеров) удалена — белый список единый,
  `systemState.phones`, фронтенд (PhonePage) уже поддерживал флаги SMS/звонок.
- Всё неблокирующее: init модуля — state machine внутри handleGSM(); ни одного
  delay/блокирующего чтения в loop() (блокировки роняют приём радио — см. lessons).
- Неизвестные номера: звонок сбрасывается (ATH) и логируется warning; SMS логируется.
- Проверено сборкой; на железе НЕ проверено (модуль не подключён) — при первом
  запуске смотреть Serial: строки "[GSM] << ..." покажут весь диалог с SIM800L.
- TinyGSM из lib_deps не используется (сырые AT прозрачнее); оставлен в конфиге.

---

## 2026-07-28 — Аудит силовой разводки во вьюере платы

- [x] board.json: ACOUT к южному краю (рядом с NO реле), FU1 горизонтально, перемычки 220 пересчитаны
- [x] board.json: кабель к приводу = 3 жилы (открыть/закрыть/общий), гермовводы в южной стенке по case.scad
- [x] viewer.js: навесные жилы огибают корпуса сбоку (chooseWrap), внешние кабели заходят в зажимы с торца
- [x] viewer.js: цвет чёрной жилы «закрыть» (L2), гермовводы рисуются на высоте проёма
- [x] validate.py OK + build.mjs + визуальная проверка в браузере (виды сверху/юг/север, консоль чистая)
- [x] Доки: board/README (RS-15-12/J1 убраны), connections.md (островок 16–36), case.scad (роли гермовводов поменяны)

**Ревью:** клеммники стоят зажимами к южному краю; кабель щитка (L/N) и кабель привода
(3 жилы: открыть-коричневая, закрыть-чёрная, общий-синяя) спускаются от гермовводов вдоль
стенки и заходят в зажимы с торца. Перемычки 220 на плате прижаты к текстолиту и огибают
корпуса сбоку (низкие коридоры между рядами 31–33 и щелями между корпусами), протыканий нет.
Гермовводы в case.scad не двигались — поменялись только роли (привод x=52, щиток x=88),
геометрия корпуса не изменилась.

### Дополнение (та же сессия): разводку 220 не видно за корпусами
- [x] «Рентген»-след для жил 220 В: полупрозрачный дубль трубки рисуется сквозь корпуса
      (depthTest off) — маршрут читается из любого ракурса; то же для кабелей корпуса
- [x] Клик по жиле / цепи в списке — весь путь подсвечивается, остальное гаснет до 7%
- [x] Подпись жилы L2 в инфопанели, обновлённые подсказки HUD
- [x] Пересборка + проверка: следы видны с севера сквозь держатель и модуль, консоль чистая

### Дополнение 2: силовые подняты в видимый жгут (как нижняя разводка, только сверху)
- [x] Все перемычки 220 — высокий пролёт: взлёт сбоку от корпуса → полёт выше корпусов (мин. 14 мм) → спуск сбоку к пятачку
- [x] Рентген-след оставлен как страховка для перекрытых участков
- [x] Тексты: board.json meta.wiring, board/README, подсказки HUD
- [x] Проверка: юг/север/сверху — маршрут каждой жилы читается, протыканий нет, консоль чистая

### Дополнение 3 (финальное решение): ВСЯ разводка — под платой
- [x] Все mains-цепи переведены на side:"bottom" — сверху платы только компоненты
- [x] 220 В идёт под платой строго в пределах островка 220 (лак с обеих сторон после пайки)
- [x] Рентген-след у цепей платы убран (консистентность с остальной нижней разводкой);
      «Просветить плату» показывает всё с верхнего ракурса
- [x] Внешние кабели без изменений: с торца в зажимы клеммников
- [x] P12V: ветка на катоды D1/D2 теперь с ножки катушки (одна точка подачи 12 В на реле)
- [x] Тексты: meta.wiring, зона 220, шаг 10, легенда, README, connections.md
- [x] Проверка: вид снизу — сеть 220 в стиле остальной разводки; сверху чисто; консоль без ошибок

### Дополнение 4: цоколёвки по даташитам (поймано пользователем)
- [x] K1/K2 (HF46F): контакты разнесены вдоль корпуса — COM в ~11.5 мм от катушки (кол. 16, северный ряд),
      NO ещё ~7 мм (кол. 19, южный ряд); тела реле сужены до 3 рядов (7.6 ≈ 7.2 мм)
- [x] U4/U5 (LM2596): пятачки по углам — вход на одном торце, выход на другом, плюсы на южном крае;
      U4 развёрнут входом к магистрали 12 В, выходом к C1/SIM800L (короткий путь пиков 2 А)
- [x] Перемычки/маршруты пересчитаны (P12V, P4V, P5V, GND_SIM, MAINS_*), валидатор OK, вьюер пересобран

### Дополнение 5: выход понижайки 5 В — парой
- [x] Земля к ESP32 идёт парой с +5 В с выходных углов U5 (OUT− → GND ESP32)
- [x] Луч «логика» от звезды убран (была бы петля); к звезде U5 подключена минусом входа
- [x] STAR: лучей три (силовой, GSM, вход понижайки 5 В), нота/шаг 5/README обновлены
- [x] Валидатор OK, вьюер пересобран, цепь GND_LOGIC проверена подсветкой

### Дополнение 6: многоагентное ревью модели (47 агентов, wf_c0f2b67d-ec8)
17 подтверждённых находок применены:
- [x] ESP32: гребёнки были перепутаны местами (север↔юг); теперь север = силовой ряд (5V…3V3),
      юг = сигнальный (CLK…IO23, GND); межрядное 25.4 мм (V4, ряды 5/15), все 38 пинов в модели;
      все 14 маршрутов пересажены
- [x] Реле HF46F: контакты в одну линию вдоль южного края (по даташиту Hongfa: катушка → 11.5 мм →
      NO (кол.16) → 7 мм → COM (кол.19, подвижный)); перемычка COM–COM по колонке 19
- [x] IRM-10-12: реальный корпус Case 222A 45.7×25.4×21.5 (был чужой 33×20), 0.85 А/10.2 Вт,
      асимметричный пинаут (L и −V южные, N +10.75, +V +8); звезда сдвинута на колонки 52–56
- [x] SIM800L: порядок пинов был зеркальный; теперь NET,VCC,RST,RXD,TXD,GND (запад→восток)
- [x] Делитель UART: 10к → 5.6к (2.2 В было впритык к VIH 2.1 В; стало ≈2.6 В)
- [x] ACOUT/ACIN сдвинуты на колонку восточнее (зазор от корпуса K2)
- [x] FU1: держатель top-loading (Stelvio PTF/78), вставка T3.15A медленная керамика
- [x] connections.md синхронизирован (BOM, делитель, общий провод привода)
- [x] Валидатор OK, вьюер пересобран, консоль чистая
- [x] Вторая партия верификации: +6 подтверждённых (4 дубля уже были применены), 2 опровергнуты,
      9 без вердикта (лимит сессии) — проверены локально и применены выборочно:
      - [x] GND_PWR: луч больше не идёт сквозь ножки Q2 (отвод [2,31]→[3,31] от магистрали кол. 2)
      - [x] Радиосторона: вертикали ушли с колонок 54–55 (антенный фидер) на 44–49;
            подход к западной колонке пинов CC1101 — с запада, не сквозь колонку 48
      - [x] Точки ветвления добавлены вэйпоинтами (GND_SIM [4,15]/[4,14], P12V [18,26])
      - [x] connections.md: честный зазор островка (~7.6 мм + прорезь + лак вместо заявленных 12.7)
      - [x] Локальный скрипт: 0 сегментов сквозь чужие пины; валидатор OK; вьюер пересобран
      - [x] Дозапуск 18 скептиков: итог всего ревью — 34 находки, 23 подтверждены (ВСЕ применены),
            11 опровергнуты (из них 9 — «дефект уже устранён в рабочей копии»: независимое
            подтверждение моих локальных фиксов). Полировка: вертикаль SPI_SCK с кол. 53 на 51
            (10 мм от антенного фида вместо 5). Сквозных проходов через чужие пины — 0.

### Дополнение 7: однослойная разводка без наложений
- [x] lint_routes.py — новый линт: наложения рёбер, общие пайки, перекрёстки, островок 220, дорожки
- [x] Каждая цепь — своя полоса: ряд 26 только 12 В, ряд 25 силовая земля, ряд 22 луч понижайки 5 В,
      ряд 18 земля GSM; драйверы по колонкам 13/14; убраны дубли рёбер внутри P12V/P3V3
- [x] Итог линта: 139 сегментов, 0 наложений, 0 общих паек, 50 перпендикулярных перекрёстков
- [x] Каждая логическая цепь — свой цвет (net.color, 24 цепи), mains — по цвету жилы
- [x] Разделение «дорожка/провод»: 16 дорожек (голая лужёнка, пайка на каждом пятачке,
      кладутся первыми), 37 проводов; 220 В — только изолированный ПуГВ
- [x] Вьюер: серебряные дорожки с каплями припоя, янтарные кольца перекрёстков, легенда,
      маркировка в инфопанели; README «Как читать разводку»; шаги 5/7 обновлены

### Дополнение 8: «сделай все» + мобильная версия + публикация
- [x] PE-клемма: ACIN → KF301-3P (L/N/PE), жёлто-зелёная жила из щитка (парковка/транзит);
      PWR сдвинут на [34..51], звезда на [53..57]
- [x] Тестовые точки TP12/TP5/TP4/TP33/TPG (петли для щупов) + LED 12 В с резистором 1к у звезды
      (NET-LED не нужен: у SIM800L штатный NETLIGHT на модуле)
- [x] Вкладка «Монтаж»: чек-лист всех 60 соединений с localStorage и подсветкой по клику
- [x] gen_sheets.py → assembly-sheets.html: нарезка (длины с запасом), зеркальный чертёж низа,
      верх, полный лист прозвонки (30 цепей + 17 пар изоляции)
- [x] Координатная линейка в 3D (каждые 5 отверстий, видна с обеих сторон)
- [x] Овальные пятачки по фото реальной платы: длинные края, поперёк кромки, НЕ спаренные —
      запрет колонок 1/58 снят (validate.py: joined=false)
- [x] Мобильная версия: панели-шторки снизу (эксклюзивное раскрытие), пинч-зум/пан двумя пальцами,
      компактный топбар, touch-action, кадрирование над шторками, pixelRatio 1.6
- [x] Лендинг в корне (index.html) для GitHub Pages

### Дополнение 9: минус тестпоинты, плюс видимость снизу
- [x] Тестовые петли TP12/TP5/TP4/TP33/TPG убраны (компоненты, ветки цепей, билдер);
      прозвонка переориентирована на пайки снизу (клеммники, узел звезды, выходы понижаек)
- [x] У каждого вывода — пайка на нижней стороне (хвостик ножки + капля припоя)
- [x] У модулей на гребёнках (ESP32, SIM800L, CC1101) — пунктирный контур гнезда и подпись
      с нижней стороны: при пайке снизу видно, где они стоят

### Дополнение 10: край платы по макро-фото
- [x] Овалы — на КОРОТКИХ сторонах (кол. 1 и 58), поперёк кромки, независимые; на длинных их нет
- [x] Буквенная сторона (A–K у овалов) = сторона GSM = западный край вьюера; буквы отрисованы
      в 3D и на чертежах; восточная сторона — овалы без букв
- [x] Раскладка ужата до колонки ≤55 (заводская нумерация 01–55 намекает, что колонок может
      быть 55): PWR → [33..50], звезда → [51..55], LED → [43..49], лучи пересчитаны
- [x] Крепёж врезается в сетку: валидатор запрещает пины/маршруты ближе r+1.2 мм от крепежа;
      GND_PWR обходит юго-западный угол через колонку 4; отверстия отрисованы на чертежах
- [x] Подтверждено пользователем: 55 отверстий по длине, овалы вне нумерации → сетка
      переведена на заводскую систему: колонки 1–55 = напечатанные 01–55, овалы = «кол. 0/56»;
      вся раскладка сдвинута на колонку запад, доки/линт/листы синхронизированы

### Дополнение 11: буквы = полный алфавит, рядов 37
- [x] Буквы у западного края: по ОДНОЙ на ряд, A–Z затем снова A–K (было: через ряд циклом A–K)
- [x] 26+11=37 → сетка ужата до 55×37 (ряд 38 не существовал; занят был только рамками зон)
- [x] gridOffset по Y пересчитан (4.3 мм), островок 220 = ряды 27–37, доки/линт/листы синхронизированы

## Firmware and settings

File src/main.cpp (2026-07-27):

#include <Arduino.h>
#include <WiFi.h>
#include <WebServer.h>
#include <Preferences.h>
#include <ArduinoJson.h>
#include <SPIFFS.h>
#include <ESPmDNS.h>
#include <WebSocketsServer.h>
#include <Update.h>
#include <algorithm>
#include <vector>
#include <nvs_flash.h>
#include <nvs.h>

// Подключение кастомных модулей
#include "CC1101Manager.h"
#include "GateControl.h"
#include "GSMManager.h"
#include "infrastructure/Logger.h"

// --- Константы пинов ---
// Пины для CC1101 (SPI + управляющие)
#define CC1101_CS   5  // GPIO5  - Chip Select (CSN)
#define CC1101_GDO0 4  // GPIO4  - Data Output (основной)
#define CC1101_GDO2 2  // GPIO2  - Преамбула (для нестандартных брелков)
// SPI пины (стандартные для ESP32):
// SCK  - GPIO18
// MISO - GPIO19
// MOSI - GPIO23

// Пины управления воротами: два реле HF46F-G через NPN-ключи (BC337 + 1 кОм + 1N4007)
#define GATE_OPEN_PIN  12 // GPIO12 - ключ реле K1: канал «открыть»
#define GATE_CLOSE_PIN 13 // GPIO13 - ключ реле K2: канал «закрыть»

// Пины для GSM SIM800L (UART2)
#define GSM_RX_PIN  16 // GPIO16 - RX пин для UART2 (подключается к TX GSM модуля)
#define GSM_TX_PIN  17 // GPIO17 - TX пин для UART2 (подключается к RX GSM модуля)

// --- Глобальные объекты ---
Preferences preferences; // Для сохранения данных в NVS
WebServer server(80); // Веб-сервер на порту 80
WebSocketsServer webSocket(81); // WebSocket сервер на порту 81

// --- Структуры данных ---
struct PhoneEntry {
  String number;
  bool smsEnabled;
  bool callEnabled;
};

struct KeyEntry {
  uint32_t code;              // Младшие 32 бита кода (для совместимости)
  String name;                // Имя ключа
  bool enabled;               // Активен ли ключ
  String protocol;            // Протокол (CAME, Keeloq, Princeton и т.д.)
  String bitString;           // Полная битовая строка (для точного сравнения)
  int bitLength;              // Количество бит
  float te;                   // Базовый период (Time Element) в мкс
  float frequency;            // Частота в МГц
  String modulation;          // Модуляция (AM650, FM476 и т.д.)
  String rawData;             // RAW данные (для отображения)
  int rssi;                   // RSSI при обучении
  unsigned long timestamp;    // Время добавления
};

struct WiFiNetwork {
  String ssid;
  int rssi;
  int encryption;
};

// Структура для отслеживания распознавания ключей (верификация сигнала)
struct KeyRecognition {
  uint32_t code;
  String protocol;
  String bitString;
  int repeatCount;
  unsigned long firstSeen;
  unsigned long lastSeen;
  float frequency;
  int requiredRepeats;
  int lastRssi;
  bool fullDecode;
  float te;
  
  KeyRecognition()
    : code(0), repeatCount(0), firstSeen(0), lastSeen(0), frequency(0.0f),
      requiredRepeats(2), lastRssi(0), fullDecode(false), te(0.0f) {}
};

// Единая структура состояния системы
struct SystemState {
  std::vector<PhoneEntry> phones;
  std::vector<KeyEntry> keys433;
  String wifiSSID;
  String wifiPassword;
  bool wifiConnected;
  bool learningMode;
  float currentFrequency;
  float bitRate;
  float freqDeviation;
  float rxBandwidth;
  int outputPower;
  uint32_t gateOpenCount;

  // Тайминги цикла ворот, сек (NeoRelay2: открытие → открыто → закрытие)
  int gateOpenSec = 3;
  int gateStaySec = 15;
  int gateCloseSec = 3;

  // Временное хранилище для верификации сигналов
  std::vector<KeyRecognition> pendingRecognitions;
};

// --- Ring-buffer лог файл ---
// Хранит последние N строк в SPIFFS, автоматически удаляет старые
namespace RingLog {
  static const char* LOG_FILE = "/log.txt";
  static const size_t MAX_LOG_SIZE = 32768; // 32KB макс размер файла
  static const size_t TRIM_TO_SIZE = 24576; // Обрезаем до 24KB когда превышен лимит

  void append(const char* message) {
    File f = SPIFFS.open(LOG_FILE, "a");
    if (!f) return;

    // Формируем строку лога с uptime
    unsigned long sec = millis() / 1000;
    char timeBuf[16];
    snprintf(timeBuf, sizeof(timeBuf), "[%luh%02lum] ", sec / 3600, (sec % 3600) / 60);
    f.print(timeBuf);
    f.println(message);
    size_t sz = f.size();
    f.close();

    // Если файл превысил лимит — обрезаем (удаляем начало, оставляем конец)
    if (sz > MAX_LOG_SIZE) {
      File rf = SPIFFS.open(LOG_FILE, "r");
      if (!rf) return;
      // Пропускаем начало файла
      rf.seek(sz - TRIM_TO_SIZE);
      // Ищем начало следующей строки
      while (rf.available()) {
        if (rf.read() == '\n') break;
      }
      String tail = rf.readString();
      rf.close();
      // Перезаписываем файл
      File wf = SPIFFS.open(LOG_FILE, "w");
      if (wf) {
        wf.print("--- лог обрезан ---\n");
        wf.print(tail);
        wf.close();
      }
    }
  }
}

// --- Хранилище данных ---
SystemState systemState;
std::vector<WiFiNetwork> wifiNetworks;

// История обнаруженных сигналов (для remove duplicates)
struct RecentDetection {
  String protocol;
  uint32_t code;
  String bitString;
  uint32_t hash;
  unsigned long firstSeen;
  unsigned long lastSeen;
  int count;
};

static std::vector<RecentDetection> detectionHistory;

// --- Объявления функций ---
void sendWebSocketEvent(const char* event, const char* data);
void sendLog(String message, const char* type);
bool saveSystemState();
void loadSystemState();

// Функция улучшенного сравнения ключей (как во Flipper Zero)
bool isKeyMatch(const KeyEntry& saved, const ReceivedKey& received, const String& receivedBitString, int receivedBitLength, float receivedTe);
// Функция сравнения битовых строк с допуском
bool compareBitStrings(const String& str1, const String& str2, float minSimilarity = 0.95f);
// Функция верификации сигнала (требует повторения)
bool verifyKeySignal(const ReceivedKey& received, const String& bitString, int bitLength, float te, bool learningMode = false);
// Очистка истории обнаруженных сигналов
void cleanupDetectionHistory();
// Проверка дубликатов (как remove duplicate во Flipper)
bool isDuplicateForDisplay(const ReceivedKey& key);

// --- WebSocket функции ---
void webSocketEvent(uint8_t num, WStype_t type, uint8_t * payload, size_t length) {
  switch(type) {
    case WStype_DISCONNECTED:
      Serial.printf("[WebSocket] Клиент %u отключен\n", num);
      break;
    case WStype_CONNECTED:
      {
        IPAddress ip = webSocket.remoteIP(num);
        Serial.printf("[WebSocket] Клиент %u подключен из %d.%d.%d.%d\n", num, ip[0], ip[1], ip[2], ip[3]);
        
        // Отправляем приветственное сообщение новому клиенту
        String welcomeMsg = "🌐 Клиент подключен: " + String(ip[0]) + "." + String(ip[1]) + "." + String(ip[2]) + "." + String(ip[3]);
        sendLog(welcomeMsg, "success");
      }
      break;
    case WStype_TEXT: {
      // Троттлинг: печать каждого кадра топила Serial (шли сотни кадров в секунду).
      // Раз в секунду — сводка: сколько кадров пришло и содержимое последнего.
      static unsigned long wsTextWindowStart = 0;
      static uint32_t wsTextCount = 0;
      wsTextCount++;
      if (millis() - wsTextWindowStart > 1000) {
        Serial.printf("[WebSocket] Кадров за окно: %u, последний (%u байт): %.80s\n",
                      wsTextCount, (unsigned)length, (const char*)payload);
        wsTextWindowStart = millis();
        wsTextCount = 0;
      }
      break;
    }
    default:
      break;
  }
}

// Экранирование строки для безопасной вставки в JSON вручную.
// Без него кавычка/бэкслеш в имени ключа, SSID или тексте лога ломали JSON.parse
// на фронтенде — событие молча терялось.
String jsonEscape(const String& s) {
  String out;
  out.reserve(s.length() + 8);
  for (unsigned int i = 0; i < s.length(); i++) {
    char c = s[i];
    switch (c) {
      case '"':  out += "\\\""; break;
      case '\\': out += "\\\\"; break;
      case '\n': out += "\\n";  break;
      case '\r': out += "\\r";  break;
      case '\t': out += "\\t";  break;
      default:
        if ((unsigned char)c < 0x20) {
          char buf[7];
          snprintf(buf, sizeof(buf), "\\u%04x", (unsigned char)c);
          out += buf;
        } else {
          out += c;
        }
    }
  }
  return out;
}

void sendWebSocketEvent(const char* event, const char* data) {
  String json = "{\"event\":\"" + String(event) + "\",\"data\":" + String(data) + "}";
  webSocket.broadcastTXT(json);

}

void sendLog(String message, const char* type = "info") {
  String logData = "{\"message\":\"" + jsonEscape(message) + "\",\"type\":\"" + jsonEscape(String(type)) + "\"}";
  sendWebSocketEvent("log", logData.c_str());
}

// --- Функции веб-сервера ---
void handleRoot() {
  if (SPIFFS.exists("/index.html")) {
    File file = SPIFFS.open("/index.html", "r");
    server.streamFile(file, "text/html");
    file.close();
  } else {
    server.send(404, "text/plain", "index.html not found");
  }
}

// Обработка WiFi сканирования
void handleWiFiScan() {
  Serial.println("[API] WiFi Scan запрошен");
  sendLog("🔍 Сканирование WiFi сетей...", "info");
  
  int n = WiFi.scanNetworks();
  wifiNetworks.clear();
  sendLog("📡 Найдено сетей: " + String(n), "success");
  
  JsonDocument doc;
  JsonArray networks = doc.to<JsonArray>();
  
  for (int i = 0; i < n; i++) {
    JsonObject network = networks.add<JsonObject>();
    network["ssid"] = WiFi.SSID(i);
    network["rssi"] = WiFi.RSSI(i);
    network["encryption"] = (WiFi.encryptionType(i) == WIFI_AUTH_OPEN) ? 0 : 1;
    
    WiFiNetwork wifiNet;
    wifiNet.ssid = WiFi.SSID(i);
    wifiNet.rssi = WiFi.RSSI(i);
    wifiNet.encryption = (WiFi.encryptionType(i) == WIFI_AUTH_OPEN) ? 0 : 1;
    wifiNetworks.push_back(wifiNet);
  }
  
  String response;
  serializeJson(doc, response);
  server.send(200, "application/json", response);
}


// Обработка подключения к WiFi
void handleWiFiConnect() {
  if (server.method() != HTTP_POST) {
    server.send(405, "text/plain", "Method Not Allowed");
    return;
  }
  
  JsonDocument doc;
  DeserializationError parseErr = deserializeJson(doc, server.arg("plain"));
  if (parseErr) {
    server.send(400, "application/json", "{\"success\":false,\"error\":\"Некорректный JSON\"}");
    return;
  }

  String ssid = doc["ssid"].as<String>();
  String password = doc["password"].as<String>();

  if (ssid.length() == 0) {
    server.send(400, "application/json", "{\"success\":false,\"error\":\"SSID не задан\"}");
    return;
  }

  Serial.println("[API] Попытка подключения к WiFi: " + ssid);

  // ВАЖНО: креды НЕ сохраняем до успешного подключения. Иначе пустое/битое тело
  // или опечатка в пароле безвозвратно затирали рабочую сеть в userdata.
  WiFi.begin(ssid.c_str(), password.c_str());

  int attempts = 0;
  while (WiFi.status() != WL_CONNECTED && attempts < 20) {
    delay(500);
    Serial.print(".");
    attempts++;
  }

  JsonDocument response;
  if (WiFi.status() == WL_CONNECTED) {
    // Сохраняем только заведомо рабочие креды
    systemState.wifiSSID = ssid;
    systemState.wifiPassword = password;
    systemState.wifiConnected = true;
    saveSystemState();

    response["success"] = true;
    response["ip"] = WiFi.localIP().toString();
    response["ssid"] = WiFi.SSID();
    response["rssi"] = WiFi.RSSI();
    Serial.println("\n[WiFi] Подключено! IP: " + WiFi.localIP().toString());
    sendLog("✅ WiFi подключен: " + WiFi.localIP().toString(), "success");
    
    // Отправляем обновление статуса через WebSocket
    String wifiStatus = "{\"status\":\"connected\",\"ssid\":\"" + jsonEscape(WiFi.SSID()) + "\",\"rssi\":" + String(WiFi.RSSI()) + ",\"ip\":\"" + WiFi.localIP().toString() + "\"}";
    sendWebSocketEvent("wifi_status", wifiStatus.c_str());
  } else {
    response["success"] = false;
    response["error"] = "Connection failed";
    Serial.println("\n[WiFi] Ошибка подключения");
    sendLog("❌ Ошибка подключения к WiFi: " + ssid, "error");
  }
  
  String responseStr;
  serializeJson(response, responseStr);
  server.send(200, "application/json", responseStr);
}

// Инициализация раздела userdata (вызывается один раз в setup)
void initUserDataPartition() {
  esp_err_t err = nvs_flash_init_partition("userdata");
  if (err == ESP_ERR_NVS_NO_FREE_PAGES || err == ESP_ERR_NVS_NEW_VERSION_FOUND) {
    // Раздел повреждён — форматируем и инициализируем заново
    Serial.println("[NVS] Форматирование раздела userdata...");
    nvs_flash_erase_partition("userdata");
    err = nvs_flash_init_partition("userdata");
  }
  if (err != ESP_OK) {
    Serial.printf("[NVS] ОШИБКА инициализации userdata: %s\n", esp_err_to_name(err));
  } else {
    Serial.println("[NVS] Раздел userdata инициализирован");
  }
}

// Сохранение строки в раздел userdata
bool saveToUserData(const char* key, const String& value) {
  nvs_handle_t handle;
  esp_err_t err = nvs_open_from_partition("userdata", "state", NVS_READWRITE, &handle);
  if (err != ESP_OK) {
    Serial.printf("[NVS] Ошибка открытия userdata: %s\n", esp_err_to_name(err));
    return false;
  }
  err = nvs_set_blob(handle, key, value.c_str(), value.length() + 1);
  if (err == ESP_OK) {
    nvs_commit(handle);
  }
  nvs_close(handle);
  return err == ESP_OK;
}

// Чтение строки из раздела userdata
String loadFromUserData(const char* key) {
  nvs_handle_t handle;
  esp_err_t err = nvs_open_from_partition("userdata", "state", NVS_READONLY, &handle);
  if (err != ESP_OK) {
    return "{}";
  }
  size_t required_size = 0;
  err = nvs_get_blob(handle, key, NULL, &required_size);
  if (err != ESP_OK || required_size == 0) {
    nvs_close(handle);
    return "{}";
  }
  char* buf = (char*)malloc(required_size);
  if (!buf) {
    nvs_close(handle);
    return "{}";
  }
  err = nvs_get_blob(handle, key, buf, &required_size);
  String result = (err == ESP_OK) ? String(buf) : String("{}");
  free(buf);
  nvs_close(handle);
  return result;
}
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
void loop() {
  // Обработка веб-запросов
  server.handleClient();

  // Обработка WebSocket
  webSocket.loop();

  // Неблокирующее обслуживание импульса ворот (выключение реле по таймеру)
  GateControl::update();
  broadcastGateStatus();

  // Периодический сброс счётчика открытий во флеш (см. persistGateCountThrottled)
  static unsigned long lastGateCountFlush = 0;
  if (gateCountDirty && millis() - lastGateCountFlush > GATE_COUNT_SAVE_INTERVAL_MS) {
    lastGateCountFlush = millis();
    if (saveSystemState()) { gateCountDirty = false; lastGateCountSave = millis(); }
  }

  // Периодическая отправка статуса WiFi и переподключение (каждые 5 секунд)
  static unsigned long lastWiFiUpdate = 0;
  static bool wasConnected = false;

  if (millis() - lastWiFiUpdate > 5000) {
    lastWiFiUpdate = millis();

    if (WiFi.status() == WL_CONNECTED) {
      // Отправляем статус подключения
      String wifiStatus = "{\"status\":\"connected\",\"ssid\":\"" + jsonEscape(WiFi.SSID()) + "\",\"rssi\":" + String(WiFi.RSSI()) + ",\"ip\":\"" + WiFi.localIP().toString() + "\"}";
      sendWebSocketEvent("wifi_status", wifiStatus.c_str());
      
      if (!wasConnected) {
        wasConnected = true;
        Serial.println("[WiFi] Успешное подключение к: " + WiFi.SSID());
      }
    } else {
      // Если было подключение, пытаемся переподключиться — но не чаще раза в 30с.
      // Вызов WiFi.begin() каждые 5с перезапускал ассоциацию, не давая ей завершиться.
      static unsigned long lastReconnectAttempt = 0;
      if (systemState.wifiSSID.length() > 0) {
        if (wasConnected) {
          Serial.println("[WiFi] Соединение потеряно, попытка переподключения к: " + systemState.wifiSSID);
          sendLog("⚠️ WiFi отключен, переподключение к " + systemState.wifiSSID + "...", "warning");
          wasConnected = false;
        }
        if (millis() - lastReconnectAttempt > 30000) {
          lastReconnectAttempt = millis();
          WiFi.begin(systemState.wifiSSID.c_str(), systemState.wifiPassword.c_str());
        }
      }
      
      // Отправляем статус отключения
      String wifiStatus = "{\"status\":\"disconnected\"}";
      sendWebSocketEvent("wifi_status", wifiStatus.c_str());
    }
  }

  // RSSI стриминг в WebSocket (режим обучения — для визуализатора сигнала)
  static unsigned long lastRssiStream = 0;
  if (systemState.learningMode && millis() - lastRssiStream > 200) {
    lastRssiStream = millis();
    int rssi = CC1101Manager::getRSSI();
    String rssiEvent = "{\"rssi\":" + String(rssi) + ",\"freq\":" + String(CC1101Manager::getFrequency()) + "}";
    sendWebSocketEvent("rssi", rssiEvent.c_str());
  }

  // Очистка устаревших распознаваний (каждые 5 секунд)
  static unsigned long lastCleanup = 0;
  if (millis() - lastCleanup > 5000) {
    cleanupOldRecognitions();
    cleanupDetectionHistory();
    lastCleanup = millis();
  }

  // Обработка CC1101 RF сигналов
  if (CC1101Manager::checkReceived()) {
    ReceivedKey receivedKey = CC1101Manager::getReceivedKey();
    
    if (receivedKey.code != 0) {
      // Используем улучшенное сравнение ключей
      KeyEntry* existingKey = nullptr;
      bool keyExists = false;
      
      for (auto& key : systemState.keys433) {
        if (isKeyMatch(key, receivedKey, receivedKey.bitString, receivedKey.bitLength, receivedKey.te)) {
          keyExists = true;
          existingKey = &key;
          break;
        }
      }
      
      if (systemState.learningMode) {
        // В режиме обучения принимаем ТОЛЬКО декодированные протоколы,
        // RAW/Unknown — это шум эфира, не сохраняем
        if (receivedKey.protocol == "RAW/Unknown" || receivedKey.protocol == "RAW/Custom") {
          // RAW/Unknown — шум эфира: НЕ логируем в Serial и НЕ шлём в UI-журнал
          // (иначе журнал захлёбывается шумом). Просто игнорируем.
          CC1101Manager::resetReceived();
          return; // Выходим из loop(), обработаем следующий сигнал на следующей итерации
        }

        Serial.println("[CC1101] Режим обучения: декодирован " + receivedKey.protocol);
        sendLog("Обнаружен: " + receivedKey.protocol + " " + String(receivedKey.bitLength) + " бит", "info");

        // Режим обучения - добавляем новый ключ с полной информацией
        if (!keyExists) {
          KeyEntry newKey;
          newKey.code = receivedKey.code;
          // Генерируем имя на основе протокола
          if (receivedKey.protocol != "RAW/Unknown") {
            newKey.name = receivedKey.protocol + "-0x" + String(receivedKey.code, HEX);
          } else {
            newKey.name = "Ключ 0x" + String(receivedKey.code, HEX);
          }
          newKey.enabled = true;
          newKey.protocol = receivedKey.protocol;
          newKey.bitString = receivedKey.bitString;
          newKey.bitLength = receivedKey.bitLength;
          newKey.te = receivedKey.te;
          newKey.frequency = CC1101Manager::getFrequency();
          newKey.modulation = receivedKey.modulation;
          newKey.rawData = receivedKey.rawData;
          newKey.rssi = receivedKey.rssi;
          newKey.timestamp = receivedKey.timestamp;
          
          systemState.keys433.push_back(newKey);

          // Выключаем режим обучения
          systemState.learningMode = false;

          // Сохраняем состояние; при сбое NVS честно сообщаем в UI, а не рапортуем успех
          bool saved = saveSystemState();

          Serial.println("[CC1101] ✅ Новый ключ добавлен: " + newKey.name);
          Serial.printf("[CC1101] Протокол: %s, Бит: %d, TE: %.1f мкс\n",
                       newKey.protocol.c_str(), newKey.bitLength, newKey.te);
          if (saved) {
            sendLog("🔑 Новый ключ добавлен: " + newKey.name, "success");
          } else {
            sendLog("⚠️ Ключ добавлен в память, но НЕ сохранён (ошибка NVS) — после перезагрузки пропадёт", "error");
          }
          
          // Отправляем событие о добавлении ключа
          String keyData = "{\"code\":" + String(receivedKey.code) +
                          ",\"name\":\"" + jsonEscape(newKey.name) + "\"" +
                          ",\"enabled\":" + String(newKey.enabled) +
                          ",\"protocol\":\"" + jsonEscape(newKey.protocol) + "\"" +
                          ",\"bitLength\":" + String(newKey.bitLength) +
                          ",\"rawData\":\"" + jsonEscape(newKey.rawData) + "\"" +
                          ",\"rssi\":" + String(newKey.rssi) +
                          ",\"frequency\":" + String(newKey.frequency) +
                          ",\"modulation\":\"" + newKey.modulation + "\"" +
                          ",\"timestamp\":" + String(newKey.timestamp) + "}";
          sendWebSocketEvent("key_added", keyData.c_str());
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

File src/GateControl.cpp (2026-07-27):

#include <Arduino.h>
#include "GateControl.h"
#include "infrastructure/Logger.h"

namespace GateControl {
  static int openPin = -1;
  static int closePin = -1;

  // Фазы цикла: открытие (канал 1) → открыто (оба выкл) → закрытие (канал 2).
  // Пошаговая логика команд: движение → STOPPED → движение в обратную сторону.
  // REVERSE_PAUSE — защитная пауза перед сменой направления:
  // мгновенный реверс мотора без мёртвого времени даёт бросок тока.
  enum class Phase { IDLE, OPENING, WAITING, CLOSING, STOPPED, REVERSE_PAUSE };
  static Phase phase = Phase::IDLE;
  static Phase nextDir = Phase::OPENING; // Куда ехать после STOPPED/REVERSE_PAUSE

  static unsigned long phaseStart = 0;     // Начало текущей фазы (millis)
  static unsigned long openDuration = 0;   // Время полного хода на открытие, мс
  static unsigned long stayDuration = 0;   // Пауза «открыто», мс
  static unsigned long closeDuration = 0;  // Время полного хода на закрытие, мс

  // Позиция створки по времени хода: 0.0 = закрыто, 1.0 = открыто.
  // Фаза движения длится остаток пути, а не полный тайминг: приоткрыли на 60% —
  // закрытие займёт 60% времени закрытия (и симметрично для недозакрытых).
  static float position = 0.0f;
  static float phaseStartPos = 0.0f;       // Позиция на входе в фазу движения
  static unsigned long phaseDuration = 0;  // Длительность текущей фазы движения, мс

  static const unsigned long REVERSE_PAUSE_MS = 500;

  // Interlock: любой активный канал включается только при выключенном втором
  static void setChannels(bool open, bool close) {
    if (open && close) return; // одновременно — никогда
    digitalWrite(openPin, open ? HIGH : LOW);
    digitalWrite(closePin, close ? HIGH : LOW);
  }

  static void enterPhase(Phase next) {
    phase = next;
    phaseStart = millis();
    switch (next) {
      case Phase::OPENING:
        phaseStartPos = position;
        phaseDuration = (unsigned long)((1.0f - position) * (float)openDuration);
        setChannels(true, false);
        Logger::success("[Ворота] Открытие (" + String(phaseDuration / 1000.0f, 1) + " с)");
        break;
      case Phase::WAITING:
        position = 1.0f;
        setChannels(false, false);
        Logger::info("[Ворота] Открыто, автозакрытие через " + String(stayDuration / 1000) + " с");
        break;
      case Phase::CLOSING:
        phaseStartPos = position;
        phaseDuration = (unsigned long)(position * (float)closeDuration);
        setChannels(false, true);
        Logger::info("[Ворота] Закрытие (" + String(phaseDuration / 1000.0f, 1) + " с)");
        break;
      case Phase::STOPPED:
        setChannels(false, false);
        Logger::warning("[Ворота] Остановлено, следующая команда — " +
                        String(nextDir == Phase::CLOSING ? "закрытие" : "открытие"));
        break;
      case Phase::REVERSE_PAUSE:
        setChannels(false, false);
        break;
      case Phase::IDLE:
        position = 0.0f;
        setChannels(false, false);
        Logger::info("[Ворота] Цикл завершен");
        break;
    }
  }

  // Зафиксировать позицию створки в момент остановки движения
  static void freezePosition() {
    unsigned long elapsed = millis() - phaseStart;
    if (phase == Phase::OPENING && openDuration > 0) {
      position = phaseStartPos + (float)elapsed / (float)openDuration;
      if (position > 1.0f) position = 1.0f;
    } else if (phase == Phase::CLOSING && closeDuration > 0) {
      position = phaseStartPos - (float)elapsed / (float)closeDuration;
      if (position < 0.0f) position = 0.0f;
    }
  }

  void init(int _openPin, int _closePin) {
    openPin = _openPin;
    closePin = _closePin;
    pinMode(openPin, OUTPUT);
    pinMode(closePin, OUTPUT);
    setChannels(false, false);
    phase = Phase::IDLE;

    Logger::success("Gate Control инициализирован (2 реле: открыть/закрыть)");
    Logger::logf("info", "[GateControl] Открыть: GPIO%d, закрыть: GPIO%d", openPin, closePin);
  }

  void startCycle(unsigned long openMs, unsigned long stayMs, unsigned long closeMs) {
    openDuration = openMs;
    stayDuration = stayMs;
    closeDuration = closeMs;

    switch (phase) {
      case Phase::IDLE:
        enterPhase(Phase::OPENING);
        break;
      case Phase::OPENING:
        // Движение прервано командой — стоп, следующая команда закроет
        freezePosition();
        nextDir = Phase::CLOSING;
        enterPhase(Phase::STOPPED);
        break;
      case Phase::CLOSING:
        // Движение прервано командой — стоп, следующая команда откроет
        freezePosition();
        nextDir = Phase::OPENING;
        enterPhase(Phase::STOPPED);
        break;
      case Phase::STOPPED:
        // Едем в обратную сторону через защитную паузу
        enterPhase(Phase::REVERSE_PAUSE);
        break;
      case Phase::WAITING:
        // Ворота открыты — команда закрывает, не дожидаясь автозакрытия
        enterPhase(Phase::CLOSING);
        break;
      case Phase::REVERSE_PAUSE:
        // Переходные 500 мс — глотаем дребезг повторных нажатий
        Logger::info("[Ворота] Переходная пауза, сигнал пропущен");
        break;
    }
  }

  void update() {
    if (phase == Phase::IDLE) return;

    // Сравнение через беззнаковое вычитание корректно переживает переполнение millis()
    unsigned long elapsed = millis() - phaseStart;

    switch (phase) {
      case Phase::OPENING:
        if (elapsed >= phaseDuration) enterPhase(Phase::WAITING);
        break;
      case Phase::WAITING:
        if (elapsed >= stayDuration) enterPhase(Phase::CLOSING);
        break;
      case Phase::CLOSING:
        if (elapsed >= phaseDuration) enterPhase(Phase::IDLE);
        break;
      case Phase::REVERSE_PAUSE:
        if (elapsed >= REVERSE_PAUSE_MS) enterPhase(nextDir);
        break;
      case Phase::STOPPED: // Стоим, пока не придёт следующая команда
      case Phase::IDLE:
        break;
    }
  }

  bool isCycleActive() {
    return phase != Phase::IDLE;
  }

  const char* phaseName() {
    switch (phase) {
      case Phase::OPENING: return "opening";
      case Phase::WAITING: return "open";
      case Phase::CLOSING: return "closing";
      case Phase::STOPPED: return "stopped";
      case Phase::REVERSE_PAUSE:
        return nextDir == Phase::CLOSING ? "closing" : "opening";
      case Phase::IDLE: break;
    }
    return "closed";
  }

  const char* nextDirName() {
    return nextDir == Phase::CLOSING ? "close" : "open";
  }

  float positionNow() {
    if (phase == Phase::OPENING && openDuration > 0) {
      float p = phaseStartPos + (float)(millis() - phaseStart) / (float)openDuration;
      return p > 1.0f ? 1.0f : p;
    }
    if (phase == Phase::CLOSING && closeDuration > 0) {
      float p = phaseStartPos - (float)(millis() - phaseStart) / (float)closeDuration;
      return p < 0.0f ? 0.0f : p;
    }
    return position;
  }
}

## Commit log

2025-11-02 Refactor RF433 receiver to CC1101 module: update documentation, remove RF433Receiver files, and implement CC1101 initialization and frequency management in main application. Update library dependenci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
2026-04-12 Rewrite frontend, add Flipper-style decoders, custom partition table
    Frontend:
    - Complete UI rewrite: dark theme design system, bottom navigation, back button
    - Real-time RSSI spectrogram in learning mode (canvas-based, live data from CC1101)
    - Frequency selector with presets directly on keys page
    - Gate status indicator (opening/open/closing/closed) with configurable timings
    - System info display (heap, uptime, RSSI)
    - Session open counter and last activity timestamp
    - WebSocket PubSub architecture — reactive updates without polling
    - Unified CSS design system, removed per-page CSS files
    Firmware:
    - Flipper Zero-style per-protocol state machine decoders (SubGhzDecoder.h)
    - CameDecoder,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
    [partitions.csv]
2026-04-12 Port 31 SubGhz protocol decoders from Flipper Zero Unleashed firmware
    Modular architecture: SubGhzDecoderBase.h + per-protocol headers.
    All decoders run in parallel via SubGhzMultiDecoder, first match wins.
    Protocols ported (each with exact TE/preamble from Unleashed source):
    - CAME (12/18/24/25/42 bit), CAME Twee (54, Manchester), CAME Atomo (62)
    - Nice FLO (12/24), Nice FlorS (52/72), Nice One (72)
    - Princeton (24), Gate TX (24)
    - Nero Radio (56), Nero Sketch (40)
    - Keeloq (64), Star Line (64)
    - Holtek HT12x (12), Linear (10)
    - Chamberlain (9), Hormann BiSecur (44)
    - FAAC SLH (64), BFT Mitto (52)
    - Somfy Telis (56, Manchester)
    - Dooya (40), Marantec (49)
    - Clemsa (18), Doitrand (37), Phoe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
2026-04-12 Add 9 more protocols from Unleashed, fix Holtek TE values — total 40 decoders
    New protocols (Batch 3):
    - Holtek HT12X (12 bit, TE=320/640)
    - Linear Delta3 (8 bit, TE=500/2000, asymmetric encoding)
    - Honeywell WDB (48 bit, TE=160/320)
    - Security+ 2.0 (62 bit, Manchester, preamble ~65ms)
    - Megacode (24 bit, PWM variable gap 2000/5000us)
    - iDo (48 bit, PWM short+long/short+short)
    - Mastercode (36 bit, TE=1072/2145)
    - Power Smart (64 bit, Manchester continuous with header pattern)
    - Somfy Keytis (80 bit, Manchester, 56+24 bit structure)
    Fixes:
    - Holtek: corrected TE from 500/1000 to 430/870 (per Unleashed source)
    - Holtek: min bits fixed from 12 to 40
    Stats: 40 decoders, RAM 17.8%, Flash 58.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
    [ProtoBatch3.h]
2026-04-12 Fix CC1101 bitrate: 3.79kbps -> 40kbps to match Flipper Zero OOK preset
    Root cause: CC1101 serial data output quantizes signal into bits.
    At 3.79kbps, bit period = 264us — longer than Nero Radio TE (200us),
    causing signal data loss. Flipper uses ~40kbps (MDMCFG4=0x2A, MDMCFG3=0x93),
    giving 25us bit period — resolves all protocols.
    RX bandwidth: 270kHz (OOK270 preset — balance of sensitivity and noise)
    Test results via Flipper CLI:
    - CAME 24-bit: OK (subghz tx)
    - Princeton 24-bit: OK (subghz tx)
    - Keeloq 64-bit: OK (tx_from_file)
    - Nice FLO, Gate TX: OK (subghz tx)
    [CC1101Manager.cpp]
2026-04-12 Real-time ring buffer decoder + exact Flipper OOK650 CC1101 registers
    Major changes:
    - ISR writes pulses to ring buffer (256 entries), main loop feeds decoders
    - Eliminates buffer overflow issue for long protocols (Nero Radio)
    - Exact CC1101 register values from Flipper OOK650Async preset via CC1101Ex subclass
    - GenericOOK ratio widened to 2:1..6:1 for CC1101 serial data output timing
    Test results (Flipper CLI TX → ESP32 RX):
    - CAME 24-bit: OK (GenericOOK)
    - Princeton 24-bit: OK (GenericOOK)
    - Keeloq 64-bit: OK (GenericOOK)
    - Nero Radio 56-bit: OK (GenericOOK) — FIRST TIME WORKING!
    All 4 protocols detected via ring buffer streaming.
    Codes need refinement (GenericOOK gives approximate m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
    [CC1101Manager.cpp]
2026-04-12 WIP: Ring buffer + Flipper OOK650 registers, register verification
    Ring buffer decoder: ISR writes to 1024-entry ring buffer, main loop
    feeds decoders in real-time (no ISR crash).
    CC1101 registers: exact Flipper OOK650Async preset applied AFTER
    RadioLib init to prevent overwrite. Verified via register readback.
    Status: CC1101 serial data output still gives uniform SHORT_H+LONG_L
    pattern regardless of OOK data content. Root cause: CC1101 serial data
    at 3.79kbps quantizes OOK transitions into 264us bits, losing the
    distinction between short (320us) and long (640us) OOK pulses.
    Next: investigate hardware timer approach or different CC1101 mode.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
    [CC1101Manager.cpp]
2026-04-12 Revert to working RadioLib config (BW=58kHz, BR=3.79kbps)
    Flipper OOK650 registers (BW=650kHz) caused uniform pulse data
    with no H/L distinction. RadioLib defaults with BW=58kHz produce
    correct OOK data with varying durations.
    Removed ring buffer (caused timing issues), back to linear buffer
    + batch Flipper-style multi-decoder.
    CAME decode verified: 0x7D852B on 434.42 MHz — correct!
    Root cause of previous failures was frequency mismatch
    (ESP32 on 434.42, Flipper TX on 433.92).
    [CC1101Manager.cpp]
2026-04-12 BREAKTHROUGH: CAME + Nero Radio + Princeton decode correctly!
    CC1101 config: bitrate=20kbps, BW=135kHz
    - 20kbps gives 50μs bit period — resolves Nero Radio TE=200μs
    - 135kHz BW balances sensitivity vs noise
    Verified with real remotes:
    - CAME 24-bit: code 0xFD852B — EXACT MATCH
    - Princeton 24-bit: code 0x123456, TE=392 — EXACT MATCH
    - Nero Radio 56-bit: codes 0x8222FD, 0x9220FD etc — rolling code decoded!
    All 40 Flipper-style protocol decoders active.
    Ring buffer removed (linear buffer + batch decode more reliable).
    [CC1101Manager.cpp]
2026-06-23 docs: sync CLAUDE.md and lessons with current decoder architecture
    - Reflect SubGhzMultiDecoder (40 Flipper-Unleashed decoders, first-match-wins)
    as the active decode path; mark ALL_PROTOCOLS[]/tryDecodeKnownProtocols legacy
    - Document userdata NVS partition (partitions.csv) surviving upload/uploadfs
    - Update radio config to 20kbps / 135kHz BW; learning mode drops RAW noise
    - Add lessons: fetch remote before committing; active decoder vs legacy
2026-06-23 tooling: add update-graph.sh for clean knowledge-graph rebuilds
    - Excludes graphify-out/, .claude/, data/static/, minified main.*.js; no HTML
    - Reuses graphify semantic cache (AST-only for code changes, no LLM)
    - Wired to a local post-commit hook (rebuilds on code changes only)
    - Replaces built-in `graphify hook` which re-added build-artifact noise
    - Lessons: document the update-graph.sh workflow
2026-07-12 fix: правки по code-review 2026-07-04 + редизайн страниц веб-интерфейса
    - CC1101Manager: устранена гонка resetReceived с живым ISR (detach → сброс
    → повторный attach), чтение data_2 для протоколов >64 бит (раньше сдвиг
    uint64 >= 64 дублировал младшие биты ключа)
    - ProtoPrinceton: корректная арифметика TE
    - Фронтенд: единый набор иконок (Icons.tsx), обновлённые страницы
    Keys/Phones/WiFi
    - Отчёты: code-review-2026-07-04, protocol-conformance-2026-06-24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
    [CC1101Manager.cpp]
2026-07-12 feat: GSM SIM800L (звонок/SMS -> ворота) + двухканальный цикл ворот
    - GSMManager: живой драйвер вместо заглушки — AT-команды по UART2,
    неблокирующий state machine PROBE->CONFIG->READY, перебор скоростей
    (9600..115200), обработка +CLIP/+CMT, автосброс звонков (ATH), сброс
    безномерных звонков по таймауту, фильтр мусора на линии. Белый список
    единый — systemState.phones (страница «Телефоны»), связь через колбэки
    gsmTrustedCheck/gsmGateOpen, сравнени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
2026-07-23 fix(cc1101): оживить приём после boot, подавить шум OOK, убрать спам RAW/Unknown
    - RX был мёртв после старта: setBitRate/setRxBandwidth/setFrequencyDeviation
    внутри RadioLib шлют CMD_IDLE и выбивают чип из direct-RX, а обёртки не
    переармливали приём. Теперь каждый сеттер завершается enterRawReceive().
    - AGC-пресет Flipper OOK650 (FIFOTHR/AGCCTRL0..2) через CC1101Ex: без него
    приёмник слайсил собственный шум (~114 ложных RAW-буферов за 8с). Стало ~20.
    - ISR: склейка спайк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
    [CC1101Manager.cpp, main.cpp]
2026-07-27 feat: пошаговый цикл ворот (стоп/реверс/позиция) + OTA-обновление из веб-интерфейса
    Цикл ворот (GateControl):
    - пошаговая логика команд как у штатных приводов: покой→открытие,
    движение→стоп (новая фаза STOPPED), из стопа→обратное движение
    через защитную паузу 500 мс; в паузе «открыто» команда закрывает
    - трекинг позиции створки (0..1) по времени хода: после стопа движение
    идёт остаток пути, а не п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
    [partitions.csv]
2026-07-28 docs(hardware): раскладка платы 10x15 + интерактивный 3D-вьюер
    - hardware/board/board.json — источник правды: 20 компонентов с пинами,
    27 цепей с маршрутами по отверстиям, зоны, 10 шагов пайки и внешние
    узлы корпуса (ввод 220 В -> предохранитель -> колодки -> БП -> J1)
    - hardware/board/index.html — самодостаточный 3D-вьюер (Three.js r147
    локально, открывается с диска): верх/низ/изометрия, слои, подсветка
    цепей кликом, пошаговая сбор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
2026-07-28 docs(hardware): кабели 220 В во вьюере раскрашены как реальные жилы
    Фаза (L) — коричневая (через предохранитель, реле), ноль (N) — синяя,
    12 В после БП — жёлтый. Метка проводника — поле conductor у связей
    enclosure в board.json; под чекбоксом внешних узлов — мини-легенда
    с пояснением ролей. В 220 В нет плюса/минуса — есть фаза и ноль.
2026-07-28 docs(hardware): детальные 3D-модели компонентов во вьюере
    Вместо параллелепипедов — узнаваемые силуэты по kind/id: ESP32 с банкой
    WROOM и меандром антенны, SIM800L красная с экраном и IPX, CC1101 с SMA,
    LM2596 с тороидом и подстроечником, реле с маркировкой HF46F-G, TO-92,
    диоды с кольцом катода со стороны пина K, резисторы с реальными цветовыми
    кольцами номинала, электролиты с полосой минуса к пину «−», клеммник с
    ви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
2026-07-28 feat(hardware): этажерка на двух платах 6x8 + корпус под 3D-печать
    Нижний ярус (board.json powerBoards): две протоплаты 6x8 — БП RS-15-12
    на первой, колодки ZK-316 (фаза/ноль) и разгрузка кабелей на второй.
    Секция enclosure сведена к стеночным элементам: гермоввод 220, держатель
    предохранителя M13 (размеры с чертежа: отверстие 13.2, тело внутрь 31 мм),
    гермоввод привода. Валидатор проверяет геометрию обоих ярусов.
    Корпус (har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
    [case.scad, case_body.stl, case_lid.stl]
2026-07-28 docs(hardware): двухъярусная сборка во вьюере + контур корпуса
    Нижний ярус из powerBoards: две платы 6x8 со своей сеткой, БП RS-15-12
    с клеммной планкой, колодки ZK-316 и разгрузка кабелей — кликабельны,
    в списке разделены подзаголовками ярусов. Кабели корпуса идут от
    стеночных узлов (гермоввод, предохранитель) к компонентам нижнего яруса
    и райзерами вверх на реле и J1 через межъярусный зазор. Опционал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
2026-07-28 feat(hardware): ревизия r2 — сетевой AC-DC модуль на плате, этажерка упразднена
    Вместо внешнего RS-15-12 и нижнего яруса из плат 6x8 — модуль HLK-15M12
    (или IRM-15-12, посадочное общее 21x12 отверстий) прямо на основной плате
    в зоне 220. Клеммник ACIN принимает фазу (после предохранителя в стенке)
    и ноль; вся сетевая коммутация — навесными проводами над платой, по меди
    220 не разводится. Шаги сборки дополнены обяз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
    [case.scad, case_body.stl, case_lid.stl]
2026-07-28 feat(hardware): r3 — IRM-10-12 на плате, сеть 220 сведена в один островок
    Блок питания: Mean Well IRM-10-12 (12 В / 10 Вт, 33.7x22.2x15) вместо
    внешнего RS-15-12. Выход 12 В совпадает с катушками реле и входами
    понижаек — гасящие резисторы не нужны (15-вольтовой версии они бы
    понадобились: 180 Ом на катушку).
    Нижняя полоса платы перекроена: раньше низковольтные драйверы были
    зажаты между двумя островками 220 (контакты реле с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
2026-07-28 feat(hardware): клеммник привода на плате + проёмы корпуса подняты над платой
    Клеммник ACOUT (3 контакта): «открыть», «закрыть» и общий. Теперь и вход,
    и выход 220 В — винтовые клеммники; наружу с платы не идёт ни один
    припаянный провод, снаружи только кабели, прикрученные винтами.
    Уточнены подписи: путь 220 один (щиток → гермоввод → предохранитель →
    клеммник ACIN на плате), а не два ввода, как чита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
    [case.scad, case_body.stl, case_lid.stl]
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2026-07-28 feat(hardware): доступ к симке и USB, предохранитель на плату
    SIM800L встаёт вертикально в угловую гребёнку PBS-R — держатель симки
    смотрит вбок и доступен при снятой крышке (альтернатива теми же шестью
    отверстиями: прямая гребёнка и модуль плашмя держателем вверх).
    ESP32 сдвинут вправо, под разъём USB-C выделен свободный коридор
    13-21/8-13: сняв крышку, кабель втыкается без разборки. Это же исправляет
    н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
    [case.scad, case_body.stl]
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2026-07-28 fix(hardware): плата описана по фактической протоплате, 220 только поверх платы
    Плата: текстолит 150x100 с зелёными полями, сетка 58x38 внутри него;
    крепёжные отверстия — в миллиметрах по углам, в поле, а не вместо
    посадочных мест (стойки корпуса переставлены под них). По двум узким
    краям — овальные попарно соединённые пятачки; колонки 1 и 58 объявлены
    непригодными, валидатор следит.
    Это вскрыло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
    [case.scad, case_body.stl]
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2026-07-28 fix(hardware): аудит платы по даташитам — реле, ESP32, IRM-10, SIM800L; вся разводка под платой
    Многоагентное ревью (79 агентов, каждый вывод — 2 независимых скептика с
    первоисточниками): 34 находки, 23 подтверждены и применены, 11 опровергнуты.
    Модель по даташитам:
    - HF46F (K1/K2): контакты в одну линию вдоль корпуса (катушка → 11.5 мм →
    NO кол.16 → 7 мм → COM кол.19), а не парой у торца; фаза на крайний вывод
    - ESP32 DevKitC: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
    [case.scad, smart-gate.kicad_sch]
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2026-07-28 fix(hardware): листы сборки — принудительно светлый фон, тёмная тема браузера их не красит
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2026-07-29 fix(hardware): край платы по макро-фото — овалы на коротких сторонах, буквы у GSM-края
    Овальные пятачки перенесены на короткие стороны (поперёк кромки, независимые),
    буквенный ряд A–K — у западного края (сторона GSM), заводская нумерация 01–55
    вдоль длинных. Раскладка ужата до колонки 55 (страховка от сетки 55×N): PWR,
    звезда, LED и лучи земли сдвинуты западнее. Крепёжные отверстия врезаются в
    сетку: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
2026-07-29 fix(hardware): сетка 55×37 — буквенная ось A–Z + A–K по одному на ряд
    Пользователь уточнил шелкографию: буквы идут на каждом ряду, полный алфавит
    A–Z и снова A–K = 37 рядов (у меня было 38 и буквы через ряд циклом A–K).
    Сетка ужата (ряд 38 занимали только рамки зон), gridOffset по Y пересчитан,
    буквы во вьюере и на чертежах — на каждом ряду, доки синхронизированы.
2026-07-29 fix(hardware): посадка по факту — ESP32 углы D21–N39, CC1101 разъём 2x4 (D-SUN 27x15)
    ESP32: пины в рядах 4/14 (D/N), колонки 21-39 — сдвиг на отверстие вверх-влево.
    CC1101: реальная цоколёвка 2x4 при SMA на восток — запад MISO/SCK/GDO0/GND,
    восток GDO2/MOSI/CSN/VCC; тело 45-55, антенна за краем. Переложено 16 маршрутов,
    развязка C3 переанкерена на новый GND_RF; линт: 147 сегментов, 66 перекрёстков, 0 ошибок.
2026-07-29 fix(hardware): корпус ESP32 по факту 27x55 мм — ряды пинов почти у краёв платы
    Тело было нарисовано 30.5x50.8; пины не менялись (D21–N39 подтверждены).
    validate.py научен дробным границам тел (габарит не кратен шагу 2.54).
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2026-07-29 fix(hardware): ESP32 — узкий клон, межрядное 22.86 мм: гребёнки в рядах 3/12 (C, 8 рядов между)
    Пользователь подтвердил физическим счётом: между гребёнками 8 свободных рядов
    (9 шагов = 22.86 мм, 0.9"), а не стандартные 25.4. Северный ряд C21–C39,
    южный — ряд 12. Переложены 9 южных маршрутов (SPI/UART/GDO/GND_RF),
    MISO ушёл на ряд 13, GDO2 на ряд 14. Линт: 147 сегментов, 64 перекрёстка, 0 ошибок.
